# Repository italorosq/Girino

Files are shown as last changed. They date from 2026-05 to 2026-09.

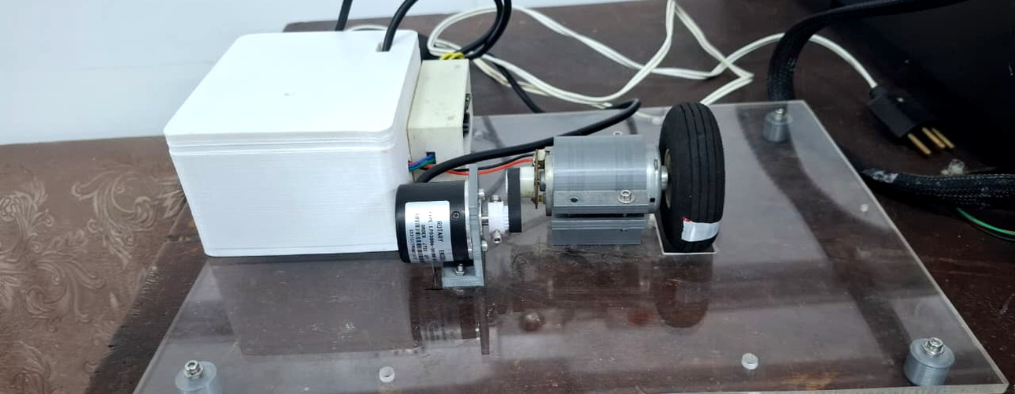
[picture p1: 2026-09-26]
docs/infografico/foto-bancada.jpg

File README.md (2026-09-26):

# Girino





Plataforma didática do **LaRA** (Laboratório de Robótica e Automação) para ensino de controle de motores DC. Integra microcontrolador com Wi-Fi, driver de potência L298N e encoder em uma bancada compacta para introdução prática à leitura de sensores, modulação PWM, controle PID e sintonia em malha fechada.

A interface web é embarcada no próprio ESP8266: o aluno conecta na rede do Girino e controla a bancada pelo navegador do celular ou notebook — sem instalar MATLAB, Python ou qualquer software, e sem depender de internet.

## Status do Projeto

| Componente | Status |
|---|---|
| Estrutura do repositório | ✅ Criada |
| Firmware (ESP8266) | ✅ Funcional — PID de velocidade/posição e auto-tune validados em bancada |
| Hardware (PCB — KiCad) | ✅ Projeto KiCad + arquivos de fabricação |
| Mecânico (caixa 3D) | ✅ Modelos STEP (caixa e tampa) |
| Documentação | ✅ |
| Exemplos didáticos | ✅ 5 exemplos |

## Funcionalidades

- **Access Point próprio** (`GIRINO_AP`, `http://192.168.4.1`) — funciona sem roteador e sem internet
- Controle PWM de motor DC via ESP8266 (4 kHz, 8 bits)
- Leitura de encoder incremental (LPD3806-600BM — 600 PPR)
- **Controle PID de velocidade (RPM) e de posição (graus)** em malha fechada
- **Auto-sintonia por relay feedback** (Åström-Hägglund) para velocidade e posição
- **Comparação de métodos de sintonia**: Ziegler-Nichols, Tyreus-Luyben e Cohen-Coon
- Interface web em 3 abas (Velocidade / Posição / Manual), com gráfico de resposta (Chart.js local) e exportação CSV
- **Console serial de comandos** — opera a bancada sem Wi-Fi
- **Auto-calibração do sentido** motor/encoder (fiação invertida corrigida em software)
- Atualização de firmware via OTA (ElegantOTA)
- Design compacto para bancada de laboratório

## Componentes de Hardware

| Componente | Descrição |
|---|---|
| ESP8266 WROOM | Microcontrolador com Wi-Fi (Access Point) |
| LPD3806-600BM | Encoder incremental, 600 pulsos/revolução (saída coletor aberto — pull-up 4,7k para 3,3 V) |
| L298N | Driver de potência do motor DC (ponte H) |
| Motor DC | Motor da bancada |
| Módulo conversão de tensão | Regulador de tensão para alimentação do circuito |

Ligações, pull-ups e montagem passo a passo em [`docs/hardware-assembly.md`](docs/hardware-assembly.md).

## Bancada Medida

| Grandeza | Valor |
|---|---|
| Zona morta do motor | ~60% de duty (abaixo disso o eixo não gira) |
| Região confiável | 70% de duty ≈ 400 RPM |
| Velocidade máxima | 100% ≈ 1950 RPM |
| Precisão de posição | ±2° (o erro residual de ~1–2° é folga mecânica da correia, não do PID) |

## Estrutura do Repositório

```
Girino/
├── firmware/          # Firmware ESP8266 (PlatformIO) + interface web (LittleFS em data/)
├── hardware/          # PCB KiCad, arquivos de fabricação (gerber/NC) e modelos 3D
├── mechanical/        # Peças 3D (em preparação)
├── docs/              # Documentação, pesquisa e infográfico
├── examples/          # Exemplos didáticos passo a passo
├── gallery/           # Fotos e renders do projeto
└── .github/           # Templates e CI/CD
```

## Início Rápido

Veja o guia completo em [`docs/getting-started.md`](docs/getting-started.md).

### Pré-requisitos

- [PlatformIO](https://platformio.org/) (extensão VSCode recomendada)
- Cabo USB para a gravação inicial do ESP8266
- Componentes e montagem: ver [`docs/hardware-assembly.md`](docs/hardware-assembly.md)

### Compilar e Gravar

```bash
cd firmware

# 1. Configurar o Access Point do Girino (SSID, senha e senha do OTA)
cp .env.example .env

# 2. Primeira gravação via USB: firmware + interface web (LittleFS)
pio run -t upload
pio run -t uploadfs

# 3. Conectar no Wi-Fi GIRINO_AP e abrir http://192.168.4.1

# 4. Atualizações seguintes via OTA (PC conectado ao GIRINO_AP)
pio run -t upload --upload-port 192.168.4.1
```

> **Importante:** `pio run -t upload` grava apenas o firmware. A interface web
> vive no LittleFS e é gravada com `pio run -t uploadfs` — obrigatório na
> primeira gravação e sempre que alterar arquivos de `firmware/data/`.

## Documentação

- [Guia de Início Rápido](docs/getting-started.md)
- [Montagem do Hardware](docs/hardware-assembly.md)
- [Guia do Firmware](firmware/README.md) — API REST, pinagem e console serial
- [Atualização OTA](docs/ota-update-guide.md)
- [Análise Comparativa](docs/analise-comparativa.md) — trabalhos relacionados e gap de pesquisa
- [Referências de Pesquisa](docs/referencias-pesquisa.md)
- [Plano PID](docs/plano-pid.md) — métodos de sintonia e arquitetura
- [Resumo UERJ Sem Muros](docs/resumo-uerj-sem-muros.md) — divulgação do projeto

## Exemplos Didáticos

| # | Exemplo | Descrição |
|---|---|---|
| 01 | [Controle Básico de Motor](examples/01-basic-motor-control/) | PWM para controlar velocidade do motor |
| 02 | [Leitura de Encoder](examples/02-encoder-reading/) | Ler pulsos e calcular velocidade |
| 03 | [Controle PID](examples/03-pid-speed-control/) | Malha fechada de velocidade |
| 04 | [OTA Web Update](examples/04-ota-web-update/) | Atualizar firmware via Wi-Fi |
| 05 | [PID Web Test](examples/05-pid-web-test/) | Teste prático de PID com painel web e gráfico |

## Contribuindo

Contribuições são bem-vindas! Veja o guia em [`CONTRIBUTING.md`](CONTRIBUTING.md).

## Licenças

Este projeto utiliza **tripla licença**:

| Tipo | Licença | Arquivo |
|---|---|---|
| Firmware (código) | **GPL-3.0** | [`LICENSE`](LICENSE) |
| Hardware (PCB, esquemático) | **CERN-OHL-S-2.0** | [`LICENSE`](LICENSE) |
| Documentação e imagens | **CC-BY-SA-4.0** | [`LICENSE`](LICENSE) |

## Equipe

Desenvolvido no **LaRA — Laboratório de Robótica e Automação** (UERJ).

## Agradecimentos

- Comunidade open-source ESP8266
- [ElegantOTA](https://github.com/ayushsharma82/ElegantOTA)
- [PlatformIO](https://platformio.org/)

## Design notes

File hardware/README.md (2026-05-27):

# Hardware — Girino

Design de PCB para a plataforma didática Girino, desenvolvido em KiCad.

## Estrutura

```
hardware/
├── kicad/          # Projeto KiCad (arquivos-fonte editáveis)
├── gerbers/        # Arquivos Gerber empacotados (.zip) para fabricação
├── bom/            # Bill of Materials (lista de materiais) em CSV
└── schematics/     # PDFs exportados do esquemático
```

## Componentes Principais

| Componente | Qtd | Descrição |
|---|---|---|
| ESP8266 WROOM | 1 | Microcontrolador Wi-Fi |
| LPD3806-600BM | 1 | Encoder incremental 600 PPR |
| Driver MOSFET | 1 | Módulo driver para motor DC |
| Regulador de tensão | 1 | Conversão de tensão para alimentação do circuito |

## Fabricação da PCB

### Gerando Gerbers no KiCad

1. Abra o projeto em `kicad/`
2. Vá em **File → Plot**
3. Selecione as camadas necessárias
4. Gere os arquivos drill
5. Empacote tudo em um `.zip` e salve em `gerbers/`

### Enviando para Fabricação

Arquivos `.zip` em `gerbers/` prontos para enviar a fabricantes como:
- [JLCPCB](https://jlcpcb.com/)
- [PCBWay](https://www.pcbway.com/)
- [Eletrrow](https://www.electrow.com/)

## Convenções

- Nomes de arquivo incluem versão: `gerbers-v1.0.zip`, `bom-v1.0.csv`
- Incluir URL do repositório no silkscreen da PCB
- Arquivos temporários de backup (`.bak`, `*-backups/`) são ignorados pelo git

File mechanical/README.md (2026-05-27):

# Peças Mecânicas — Girino

Modelos 3D para impressão da caixa/estrutura da plataforma Girino.

## Estrutura

```
mechanical/
├── cad/      # Arquivos-fonte FreeCAD (.FCStd) — editáveis
├── stl/      # Arquivos STL — prontos para impressão 3D
└── step/     # Arquivos STEP — para referência e montagem virtual
```

## Peças

| Peça | Arquivo | Descrição |
|---|---|---|
| Caixa superior | `girino-enclosure-top.stl` | Tampa da caixa protetora |
| Caixa inferior | `girino-enclosure-bottom.stl` | Base com fixações para componentes |
| Suporte encoder | `girino-encoder-mount.stl` | Suporte para fixação do encoder |

## Configurações de Impressão Recomendadas

| Parâmetro | Valor |
|---|---|
| Material | PLA ou PETG |
| Preenchimento | 20% (mínimo) |
| Perímetros | 3 |
| Altura de camada | 0.2 mm |
| Suportes | Conforme necessário |

## Editando os Modelos

1. Instale o [FreeCAD](https://www.freecad.org/)
2. Abra os arquivos `.FCStd` em `cad/`
3. Faça suas alterações
4. Exporte STL em **File → Export**
5. Salve o arquivo-fonte atualizado em `cad/`

## Convenções

- Nomes de arquivo descritivos em inglês
- STLs devem ser testados em slicer antes de commitar
- Manter arquivos STEP atualizados para referência

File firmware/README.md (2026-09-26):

# Firmware — Girino

Firmware para ESP8266 WROOM com controle PWM de motor DC, leitura de encoder e OTA.

## Requisitos

- [PlatformIO](https://platformio.org/) (CLI ou extensão VSCode)
- Cabo USB para gravação inicial
- Python 3 (para PlatformIO)

## Configuração Inicial

O Girino opera como **Access Point**: ele cria a própria rede Wi-Fi
(chamada `GIRINO_AP` por padrão) e os alunos conectam direto pelo
celular/notebook, sem precisar de roteador nem internet.

```bash
# 1. Copiar template de credenciais
cp .env.example .env

# 2. (Opcional) Ajustar nome e senha da rede criada pelo ESP:
#    WIFI_SSID="GIRINO_AP"
#    WIFI_PASSWORD="girino123"     # mínimo 8 caracteres
#    OTA_PASSWORD="senha_para_ota"
nano .env
```

Após conectar na rede do ESP, acesse `http://192.168.4.1`.

## Compilar e Gravar

### Primeira gravação (via USB)

```bash
# Compilar
pio run

# Compilar e gravar o firmware
pio run -t upload

# Gravar o filesystem (interface web em data/) — OBRIGATÓRIO na
# primeira gravação e sempre que alterar arquivos de data/
pio run -t uploadfs

# Monitor serial (Ctrl+] para sair)
pio device monitor
```

> **Importante:** `pio run -t upload` grava apenas o firmware. A interface
> web (`data/index.html`, `style.css`, `app.js`, `chart.umd.min.js`) vive
> no LittleFS e é gravada com `pio run -t uploadfs`. Se a página abrir com
> "index.html nao encontrado no LittleFS", falta o `uploadfs`.

### Console serial (controle sem Wi-Fi)

O firmware tem um console de comandos na própria porta serial — útil para
bancada, testes rápidos e quando não se quer usar o navegador. Abra o
monitor (`pio device monitor`) e digite `help`:

| Comando | Descrição |
|---|---|
| `help` | lista os comandos |
| `status` | modo, RPM, ângulo, pulsos, heap, IP |
| `enc` | leitura do encoder agora |
| `motor <fwd\|rev\|stop> [0-100]` | comando manual (cancela controladores) |
| `pid <kp> <ki> <kd> <sp>` | configura o PID de velocidade (RPM) |
| `pid start` / `pid stop` | liga/desliga a malha de velocidade |
| `pos <kp> <ki> <kd> <graus>` | configura o PID de posição |
| `pos start` / `pos stop` / `pos zero` | controle de posição / zera origem |
| `autotune <amp> <bias> <n> <sp>` | inicia o relay feedback (velocidade) |
| `autotune pos <amp> <n> <graus>` | inicia o relay feedback (posição, ±amp) |
| `autotune cancel` | cancela o experimento |
| `tune` | mostra Ku/Tu e ganhos ZN/TL/CC do último auto-tune |

Durante qualquer controlador ativo, a telemetria sai a 2 Hz no serial
(`[PID] SP/RPM/Out`, `[Pos] Alvo/Ângulo/Out`, `[AutoTune] RPM/relay`), e o
encoder reporta 1 Hz (`[Encoder] pulsos/p-s/rpm/ângulo`).

### Auto-calibração do sentido (fiação)

No primeiro movimento após o boot, o firmware aplica um pulso curto de
teste e observa a contagem do encoder:

- Contagem positiva → fiação normal (`[Motor] Sentido OK`)
- Contagem negativa → fiação invertida detectada e **corrigida em
  software** (`[Motor] Fiacao invertida detectada`) — não é preciso
  trocar fios: "horário" (FORWARD) sempre aumenta o ângulo medido

As malhas de velocidade e auto-tune usam |RPM| e funcionam com qualquer
polaridade; a calibração garante também o controle de posição.

### Atualizações subsequentes (via OTA)

Conecte o computador na rede do próprio ESP (`GIRINO_AP`) ou use a
interface web em `http://192.168.4.1/update`.

```bash
# Via OTA (computador conectado ao GIRINO_AP)
pio run -t upload --upload-port 192.168.4.1
```

> OTA e `uploadfs` não são a mesma coisa: OTA grava o **firmware**;
> alterações na interface web (pasta `data/`) exigem `pio run -t uploadfs`
> via USB.

## Arquitetura do Firmware

```
src/
├── main.cpp            # Loop principal, WiFi, web server, API REST
├── motor_control.cpp   # Controle PWM do motor
├── encoder.cpp         # Leitura do encoder via interrupção
├── pid.cpp             # Controle PID em malha fechada (50 Hz)
├── pid_autotune.cpp    # Auto-tune via relay feedback (Åström-Hägglund)
└── pid_tuning_rules.cpp # Regras de sintonia Ziegler-Nichols, Tyreus-Luyben e Cohen-Coon

include/
├── pins.h              # Mapeamento de GPIOs (centralizado)
├── config.h            # Constantes e configurações
├── motor_control.h     # Interface do módulo motor
├── encoder.h           # Interface do módulo encoder
├── pid.h               # Interface do módulo PID
├── pid_autotune.h      # Interface do auto-tune
└── pid_tuning_rules.h  # Interface das regras de sintonia
```

## API REST

| Endpoint | Método | Descrição |
|---|---|---|
| `/` | GET | Interface web de controle |
| `/api/motor` | POST | Comando do motor (`direction`, `speed`) |
| `/api/encoder` | GET | Leitura atual do encoder (`pulses`, `rpm`, `angle`) |
| `/api/status` | GET | Status (versão, heap, uptime, IP, clientes do AP, modo) |
| `/api/pid/config` | GET/POST | Configura/consulta ganhos e setpoint do PID de velocidade |
| `/api/pid/start` | POST | Inicia controle de velocidade em malha fechada |
| `/api/pid/stop` | POST | Para o PID, volta a malha aberta |
| `/api/pid/autotune` | GET/POST | Inicia/consulta experimento relay feedback (`plant=speed\|position`) |
| `/api/pid/tuning` | GET | Planta identificada (`plant`), Ku, Tu e sugestões `zn`/`tl`/`cc` |
| `/api/pid/tuning/apply` | POST | Aplica regra de sintonia (`method=ZN|TL|CC`) |
| `/api/pid/response` | GET | Última resposta ao degrau (tempo, setpoint, medida, `unit`) |
| `/api/position/config` | GET/POST | Configura/consulta ganhos e alvo do PID de posição (`target` em graus) |
| `/api/position/start` | POST | Inicia controle de posição (`target` opcional em graus) |
| `/api/position/stop` | POST | Para o controle de posição |
| `/api/position/zero` | POST | Define a posição atual como 0° (origem) |
| `/update` | GET | Interface OTA (ElegantOTA) |

### Exemplos de uso da API

```bash
# Ligar motor em 50% sentido horário (malha aberta)
curl -X POST http://192.168.4.1/api/motor -d "direction=forward&speed=50"

# Parar motor
curl -X POST http://192.168.4.1/api/motor -d "direction=stop&speed=0"

# Ler encoder
curl http://192.168.4.1/api/encoder

# Status do sistema
curl http://192.168.4.1/api/status

# Configurar PID (setpoint em RPM)
curl -X POST http://192.168.4.1/api/pid/config -d "kp=2.0&ki=5.0&kd=0.1&setpoint=100"

# Iniciar malha fechada
curl -X POST http://192.168.4.1/api/pid/start

# Iniciar auto-tune de VELOCIDADE (relay ±10% em torno de bias 90%, 3 ciclos, setpoint 100 RPM)
# O bias (pedestal) precisa vencer a zona morta do motor — o PWM mínimo
# que faz o eixo girar (medido nesta bancada: ~80%). Use `bias` entre esse
# valor e 95%, e `relay_amplitude` de forma que bias ± amplitude fique
# dentro de 0-100%.
curl -X POST http://192.168.4.1/api/pid/autotune -d "plant=speed&relay_amplitude=10&bias=90&cycles=3&setpoint=100"

# Iniciar auto-tune de POSIÇÃO (relé simétrico ±90% em torno do alvo 90°)
# O relé alterna horário/anti-horário; a amplitude precisa ficar acima da
# zona morta (~60%) para ambos os estados moverem o motor. Os ganhos
# resultantes estão em %/° (malha de posição).
curl -X POST http://192.168.4.1/api/pid/autotune -d "plant=position&relay_amplitude=90&cycles=3&target=90"

# Consultar resultado do auto-tune (inclui "plant": onde os ganhos se aplicam)
curl http://192.168.4.1/api/pid/autotune

# Aplicar Tyreus-Luyben
curl -X POST http://192.168.4.1/api/pid/tuning/apply -d "method=TL"

# Baixar resposta ao degrau
curl http://192.168.4.1/api/pid/response

# --- Controle de posição (ângulo) ---

# Zerar a posição atual (define origem 0°)
curl -X POST http://192.168.4.1/api/position/zero

# Configurar PID de posição (alvo 90°)
curl -X POST http://192.168.4.1/api/position/config -d "kp=1.0&ki=0.2&kd=0.05&target=90"

# Iniciar controle de posição
curl -X POST http://192.168.4.1/api/position/start

# Parar controle de posição
curl -X POST http://192.168.4.1/api/position/stop
```

## Pinagem

| GPIO | Pino NodeMCU | Função |
|---|---|---|
| GPIO5 | D1 | Encoder Canal A |
| GPIO4 | D2 | Encoder Canal B |
| GPIO14 | D5 | Motor Direção INB1 (alias IN3) |
| GPIO12 | D6 | Motor Direção INB2 (alias IN4) |
| GPIO13 | D7 | Motor PWM ENB |
| GPIO2 | LED | LED onboard (debug) |

> **Nota sobre o encoder:** o LPD3806 tem saída em coletor aberto — os
> canais A e B exigem resistores de pull-up externos de 4,7k para 3.3V
> (nunca 5V). Ver detalhes em [`docs/hardware-assembly.md`](../docs/hardware-assembly.md).

## Dependências

| Biblioteca | Versão | Descrição |
|---|---|---|
| ElegantOTA | ^3.1.5 | Interface web para atualização OTA |
| ESP8266WebServer | ^1.0 | Servidor HTTP embutido |

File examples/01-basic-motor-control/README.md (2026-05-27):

# Exemplo 01 — Controle Básico de Motor

Introdução ao controle PWM de um motor DC via ESP8266.

## Objetivos de Aprendizagem

- Entender o conceito de PWM (Pulse Width Modulation)
- Controlar a velocidade de um motor DC
- Controlar a direção de rotação

## Conceitos

### PWM (Modulação por Largura de Pulso)

O PWM controla a potência entregue ao motor variando o tempo que o sinal fica em nível alto (duty cycle).

- **Duty cycle 0%** → Motor parado
- **Duty cycle 50%** → Motor a meia velocidade
- **Duty cycle 100%** → Motor a velocidade máxima

### Controle de Direção

Usando dois pinos digitais de direcao (IN3 e IN4):

| IN3 | IN4 | Resultado |
|-----|-----|---|
| HIGH | LOW | Sentido horário |
| LOW | HIGH | Sentido anti-horário |
| LOW | LOW | Motor livre (parado) |
| HIGH | HIGH | Frenagem (freio) |

## Código

> Em breve — será adicionado com a implementação.

## Exercícios Propostos

1. Fazer o motor acelerar gradualmente de 0% a 100%
2. Alternar a direção a cada 3 segundos
3. Criar um "rampa" de aceleração suave

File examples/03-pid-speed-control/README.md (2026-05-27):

# Exemplo 03 — Controle PID de Velocidade

Implementação de controlador PID para manter velocidade constante do motor.

## Objetivos de Aprendizagem

- Entender o conceito de controle em malha fechada
- Implementar um controlador PID
- Sintonizar os ganhos Kp, Ki, Kd

## Conceitos

### Malha Fechada

```
  Setpoint ──→ [+] ──→ PID ──→ Motor ──→ Velocidade
                ↑ -                         │
                └──── Encoder (feedback) ───┘
```

### PID (Proporcional-Integral-Derivativo)

- **P (Proporcional):** Erro × Kp → reação proporcional ao erro
- **I (Integral):** Soma do erro × Ki → elimina erro em regime permanente
- **D (Derivativo):** Taxa de variação × Kd → amortecimento de oscilações

## Código

Este exemplo conceitual e o código executável de teste estão em:

- [`examples/05-pid-web-test/`](../05-pid-web-test/)

## Exercícios Propostos

1. Implementar apenas o P e observar o erro em regime
2. Adicionar I e eliminar o erro em regime permanente
3. Adicionar D e reduzir overshoot
4. Aplicar o método Ziegler-Nichols para sintonia
5. Testar resposta a perturbações (carga variável no motor)

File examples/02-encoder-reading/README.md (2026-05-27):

# Exemplo 02 — Leitura de Encoder

Introdução à leitura de encoder incremental LPD3806-600BM.

## Objetivos de Aprendizagem

- Entender o princípio de encoder incremental
- Ler pulsos via interrupção GPIO
- Calcular velocidade angular (RPM)

## Conceitos

### Encoder Incremental

O LPD3806-600BM gera 600 pulsos por revolução em dois canais (A e B) defasados em 90°:

- **Canal A sozinho** → Contagem de pulsos (velocidade)
- **Canais A+B** → Determinação de direção (quadratura)

### Interrupções

O ESP8266 suporta interrupções em GPIOs. Usamos interrupção no canal A e lemos o canal B na ISR para determinar a direção.

## Código

> Em breve — será adicionado com a implementação.

## Exercícios Propostos

1. Contar o número de voltas completas do motor
2. Medir a velocidade em RPM para diferentes níveis de PWM
3. Calcular a distância percorrida (se o motor aciona uma roda)

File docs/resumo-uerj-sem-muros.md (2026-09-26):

# Girino: plataforma didática de baixo custo para ensino de controle de motores DC via navegador

**Autor:** Ítalo Rosa Gonçalves
**Orientador:** Prof. Ângelo Mondaini Calvão
**Laboratório:** LaRA — Laboratório de Robótica e Automação (UERJ)
**Modalidade:** Estágio Interno Complementar
**ODS:** 4 — Educação de Qualidade

## Resumo

O ensino de controle exige prática experimental, mas bancadas comerciais são caras e as alternativas de baixo custo dependem de software proprietário ou instalações locais, restringindo o acesso dos estudantes. Alinhado ao ODS 4 (Educação de Qualidade), este trabalho desenvolve o Girino, plataforma didática de baixo custo para controle de motores DC, acessível apenas pelo navegador.

A bancada reúne microcontrolador com Wi-Fi, encoder de realimentação e driver de potência. O firmware implementa controle de velocidade e de posição em malha fechada, com auto-sintonia e comparação de métodos de sintonia. A interface web embarcada permite operar o motor e acompanhar a resposta em qualquer dispositivo, sem instalar nada, e o firmware é atualizado por OTA. O hardware também foi projetado no laboratório.

A bancada foi montada e validada: os controles de velocidade e posição operam em malha fechada, a auto-sintonia identifica o sistema e sugere ganhos, e a interface funciona sem internet. A caracterização do motor e a calibração da fiação também foram tratadas.

O Girino se mostra uma plataforma funcional e acessível, que dispensa MATLAB, Python ou qualquer instalação e facilita a manutenção das bancadas via OTA. Como continuidade, prevê-se a modelagem do sistema, a comparação experimental dos métodos e a avaliação pedagógica com alunos.

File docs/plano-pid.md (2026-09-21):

# Plano — Módulo PID e Auto-Tune

Planejamento do controle PID com auto-tune e comparação de métodos de sintonia para o artigo.

---

## 1. Métodos de Sintonia a Implementar

### Por que comparar métodos?

Todos os trabalhos relacionados usam **um único método** de sintonia, dependendo de MATLAB ou Python. Nenhum oferece comparação visual entre métodos diretamente no hardware. O Girino propõe que o aluno compare ZN, TL e CC no navegador — vendo diferenças de overshoot, tempo de acomodação e erro em regime.

### Métodos selecionados

| # | Método | Tipo | Referência | Por que incluir |
|---|---|---|---|---|
| 1 | **Ziegler-Nichols** | Regra (após relay) | Ziegler & Nichols, 1942 | Mais conhecido. Referência obrigatória em qualquer texto de controle. |
| 2 | **Tyreus-Luyben** | Regra (após relay) | Tyreus & Luyben, 1992 | Mais robusto que ZN, menor overshoot. Bom contraste didático. |
| 3 | **Cohen-Coon** | Regra (após relay) | Cohen & Coon, 1953 | Usado por Alexandre (2025) — permite comparação direta com literatura. |
| 4 | **Relay Feedback** | Auto-tune | Åström & Hägglund, 1984 | Método de identificação. Encontra Ku e Tu automaticamente. **Diferencial do Girino.** |
| 5 | **Manual** | Livre | — | Professor/aluno ajusta Kp, Ki, Kd via web. Maior valor didático. |

### Coeficientes de cada regra (a partir de Ku, Tu)

| Regra | Kp | Ti | Td |
|---|---|---|---|
| **Ziegler-Nichols** | 0.6 × Ku | Tu / 2.0 | Tu / 8.0 |
| **Tyreus-Luyben** | Ku / 2.2 | 2.2 × Tu | Tu / 6.3 |
| **Cohen-Coon** | (Ku/1.35) × (1 + Tu/(4×delay)) | Tu × f(delay) | Tu × g(delay) |

Nota: Cohen-Coon requer estimativa de atraso (dead time) — pode ser obtido via step test.

---

## 2. Fluxo de Auto-Tune (Relay Feedback)

```
Aluno clica "Auto-Tune" na interface web
       ↓
[1] Motor em velocidade nominal (setpoint inicial)
       ↓
[2] ESP8266 aplica relay: +d% se erro > 0, -d% se erro < 0
    (d = amplitude do relay, ex: 20% do PWM)
       ↓
[3] Sistema oscila em limite cycle
    Encoder mede período da oscilação → Tu (período crítico)
    Amplitude do relay × ganho do sensor → Ku (ganho crítico)
       ↓
[4] Calcula Ku e Tu pela média de N ciclos (N=3 a 5)
       ↓
[5] Oferece 3 opções de ganhos: ZN, TL, CC
    Aluno escolhe ou testa todas
       ↓
[6] PID carregado com Kp, Ki, Kd calculados
       ↓
[7] Resposta ao degrau registrada e exibida no gráfico web
       ↓
[8] Aluno pode comparar overshoot, settling time, steady-state error
```

### Parâmetros do Relay Feedback

| Parâmetro | Valor | Observação |
|---|---|---|
| Amplitude do relay (d) | 15–25% PWM | Ajustável. Motor não pode parar. |
| Número de ciclos (N) | 3–5 | Mais ciclos = mais preciso, mais demorado |
| Setpoint nominal | 50% velocidade | Ponto de operação para o experimento |
| Timeout | 30 segundos | Segurança — aborta se não oscilar |

---

## 3. Arquitetura do Firmware

### Novos arquivos

```
firmware/include/
├── pid.h                  → Estrutura PID (Kp, Ki, Kd, setpoint, limites)
├── pid_autotune.h         → Relay feedback (Ku, Tu, estado do experimento)
└── pid_tuning_rules.h     → Calcula Kp/Ki/Kd para ZN, TL, CC

firmware/src/
├── pid.cpp                → Cálculo PID com anti-windup + derivative-on-measurement
├── pid_autotune.cpp       → Máquina de estados do relay feedback
└── pid_tuning_rules.cpp   → Aplica regras de sintonia
```

### PID — Formulacao

```
Implementar forma posicional (standard):

u(t) = Kp × e(t) + Ki × ∫e(τ)dτ + Kd × de(t)/dt

Discreto (T = período de amostragem):

u[k] = Kp × e[k]
     + Ki × T × Σe[j]     (com anti-windup: clamp na integral)
     + Kd × (e[k] - e[k-1]) / T

Ou, para evitar derivative kick:
u[k] = Kp × e[k]
     + Ki × T × Σe[j]
     + Kd × (y[k] - y[k-1]) / T     (derivative on measurement)

Saída u[k] mapeada para PWM: 0 a MOTOR_PWM_RANGE (1023)
```

### Anti-windup

A integral do PID deve ser limitada para evitar saturação:
- Se `u[k] > max_output` → clamp integral em `max_output - Kp×e - Kd×de`
- Se `u[k] < min_output` → clamp integral similarmente

### Sample rate

| Taxa | Observação |
|---|---|
| 50 Hz (20 ms) | Boa para motor DC. ESP8266 aguenta facilmente. |
| 100 Hz (10 ms) | Se encoder de alta velocidade exigir. |
| 10 Hz (100 ms) | Taxa atual do encoder. Pode ser suficiente. |

**Recomendação:** 50 Hz (20ms). Encoder já amostra a 100ms — pode diminuir para 20ms no modo PID.

---

## 4. API REST — Novos Endpoints

| Endpoint | Método | Parâmetros | Descrição |
|---|---|---|---|
| `/api/pid/config` | POST | `kp`, `ki`, `kd`, `setpoint` | Configura ganhos e setpoint do PID |
| `/api/pid/config` | GET | — | Retorna config atual |
| `/api/pid/start` | POST | — | Liga controle em malha fechada |
| `/api/pid/stop` | POST | — | Desliga PID, volta a malha aberta |
| `/api/pid/autotune` | POST | `relay_amplitude`, `cycles` | Inicia experimento relay feedback |
| `/api/pid/autotune` | GET | — | Status do auto-tune (running/done/results) |
| `/api/pid/tuning` | GET | — | Retorna Ku, Tu + sugestões ZN/TL/CC |
| `/api/pid/tuning/apply` | POST | `method` (ZN/TL/CC) | Aplica regra de sintonia escolhida |
| `/api/pid/response` | GET | — | Última resposta ao degrau (array tempo, setpoint, velocidade) |

### Exemplo de uso

```bash
# 1. Iniciar auto-tune
curl -X POST http://192.168.1.100/api/pid/autotune \
  -d "relay_amplitude=20&cycles=3"

# 2. Ver resultados
curl http://192.168.1.100/api/pid/autotune
# → {"status":"done","ku":5.2,"tu":0.35}

# 3. Ver sugestões
curl http://192.168.1.100/api/pid/tuning
# → {"ku":5.2,"tu":0.35,
#     "ZN":{"kp":3.12,"ki":17.83,"kd":0.14},
#     "TL":{"kp":2.36,"ki":4.55,"kd":0.06},
#     "CC":{"kp":3.85,"ki":15.20,"kd":0.12}}

# 4. Aplicar Tyreus-Luyben
curl -X POST http://192.168.1.100/api/pid/tuning/apply \
  -d "method=TL"

# 5. Iniciar malha fechada
curl -X POST http://192.168.1.100/api/pid/start \
  -d "setpoint=50"

# 6. Coletar resposta ao degrau
curl http://192.168.1.100/api/pid/response
# → {"data":[[0,0],[0.02,5],...,[3.0,49.8]],"setpoint":50}
```

---

## 5. Interface Web — Componentes Novos

### Painel de PID (adicionar à página principal)

```
┌─────────────────────────────────────┐
│  Controle PID                       │
│                                     │
│  Setpoint: [____] RPM               │
│  Kp: [____]  Ki: [____]  Kd: [____] │
│                                     │
│  [▶ Iniciar PID]  [⏹ Parar]         │
│  [🔧 Auto-Tune]  [📊 Step Response] │
│                                     │
│  Método de sintonia:                │
│  ○ Ziegler-Nichols                  │
│  ○ Tyreus-Luyben (recomendado)      │
│  ○ Cohen-Coon                       │
│  ○ Manual                           │
│                                     │
│  ┌─────────────────────────────┐    │
│  │  Gráfico: Tempo vs RPM      │    │
│  │  (setpoint + resposta real)  │    │
│  │  ~~~~~~~~~~~~~~~~~~~~~~~~    │    │
│  └─────────────────────────────┘    │
│                                     │
│  Resultados Auto-Tune:              │
│  Ku = 5.2  Tu = 0.35s              │
│  Overshoot: 12%  Settling: 1.8s     │
└─────────────────────────────────────┘
```

### Biblioteca de gráficos

Usar **Chart.js** (CDN, leve, sem instalação):
- Gráfico de linha em tempo real
- Eixo X: tempo (s), Eixo Y: RPM
- Linha tracejada: setpoint
- Linha sólida: velocidade real
- Exportar dados como CSV

---

## 6. Estrutura Didática (Exemplos Progressivos)

| # | Exemplo | Conceito | Atividade do Aluno |
|---|---|---|---|
| 01 | Controle básico de motor | PWM, duty cycle | Variar PWM e observar velocidade |
| 02 | Leitura de encoder | Interrupção, quadratura | Contar pulsos, calcular RPM |
| 03 | Curva do motor (malha aberta) | Modelagem empírica | Aplicar PWM de 0 a 100%, plotar curva RPM vs PWM |
| 04 | PID manual | Controle em malha fechada | Ajustar Kp, Ki, Kd e observar resposta |
| 05 | Auto-tune | Identificação de sistemas | Executar relay feedback, obter Ku e Tu |
| 06 | Comparação de métodos | ZN vs TL vs CC | Aplicar cada método, comparar gráficos |

### Valor didático da comparação de métodos

O aluno aprende que:
- ZN tem resposta rápida mas muito overshoot
- TL é mais lento mas sem oscilação
- CC é intermediário
- Manual pode ser melhor se o aluno entende o sistema
- Não existe "melhor método" — depende do critério (velocidade, robustez, etc.)

---

## 7. Comparação com Trabalhos Existentes

| Aspecto | Alexandre 2025 | Cabral 2025 | MotoShield | OpenMCT | **Girino** |
|---|---|---|---|---|---|
| Método de sintonia | Cohen-Coon | z-domain (MATLAB) | MATLAB sysID | Coeficientes GUI | **Auto-tune + 3 regras + manual** |
| Auto-tune embarcado | ❌ | ❌ | ❌ | ❌ | **✅ (Relay Feedback)** |
| Comparação de métodos | ❌ | ❌ | ❌ | ❌ | **✅ (ZN vs TL vs CC)** |
| Visualização | SCADA externo | MATLAB | MATLAB | Python/Qt | **Navegador web** |
| Software necessário | SCADA | MATLAB | MATLAB | Python+Qt | **Nenhum** |

### Argumento para o paper

> "Enquanto plataformas existentes usam um único método de sintonia dependente de software externo (MATLAB, Python), o Girino implementa auto-tune embarcado via relay feedback (Åström-Hägglund) e permite comparação direta de três regras clássicas (Ziegler-Nichols, Tyreus-Luyben, Cohen-Coon) através de interface web — sem instalação de qualquer software."

---

## 8. Pendências para o Artigo (Checklist)

- [x] Levantamento bibliográfico (~70 referências)
- [x] Análise comparativa dos trabalhos relacionados
- [x] Planejamento dos métodos de sintonia
- [x] Implementar PID no firmware (pid.h + pid.cpp)
- [x] Implementar auto-tune (pid_autotune.h + pid_autotune.cpp)
- [x] Implementar regras de sintonia (ZN, TL, CC)
- [x] Adicionar endpoints API REST para PID
- [ ] Interface web com gráfico de resposta ao degrau (UI pronta; validar com hardware real)
- [ ] Modelagem matemática do sistema motor+encoder
- [ ] Testes experimentais: comparar ZN vs TL vs CC
- [ ] Avaliação pedagógica com alunos
- [ ] Redação do artigo

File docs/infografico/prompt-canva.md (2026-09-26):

# Prompt para a IA do Canva — infográfico 60 × 15 cm

Uso: no Canva Pro, crie um design em **Custom size → 60 × 15 cm**, suba `foto-bancada.jpg`, `infografico-uerj-sem-muros-60x15.png` (referência) e, no Brand Kit, as cores e as fontes de `fontes/` (Source Sans 3). Cole o prompt abaixo na IA e substitua os textos gerados pelos textos exatos do prompt. QR: Apps → QR Code → `github.com/italorosq/Girino`. Exporte PDF Print para a gráfica.

Atenção: a exportação PNG do Canva pode sair abaixo de 300 dpi; para o SDA, use o PNG de `docs/images/` (mesmo layout, 7087 × 1772 px).

---

Crie um infográfico horizontal (banner) de 60 × 15 cm, em português do Brasil, sobre um projeto acadêmico de engenharia, para a 23ª Semana de Graduação / 34ª UERJ Sem Muros. Público: banca e visitantes. Estilo institucional, técnico e sóbrio — nada infantil, nada de clip-art, sem sombras fortes nem excesso de gradientes. Fundo geral #E4EBF3; painéis brancos com borda fina #D9E3EF e cantos arredondados.

TEMA: modernização das plataformas robóticas do LaRA (Laboratório de Robótica e Automação — UERJ / CETREINA / EIC). O Girino é o PRIMEIRO MÓDULO ENTREGUE dessa modernização — não é um projeto separado.

Título (usar exatamente): "Modernização de Plataformas Robóticas e Desenvolvimento de Infraestrutura para Experimentação em Algoritmos de Robótica".

LAYOUT — 6 painéis lado a lado, com pequenos espaços entre eles (~0,1 cm) e estas larguras relativas:
1. Identidade — 15,6% (fundo azul-escuro #0B2C57, texto branco)
2. Problema — 12,7% (barra vermelha #C0392B)
3. Tese e Objetivo — 15,6% (barra azul #1660A8)
4. Método — 22,0% (barra azul #1660A8)
5. Resultados — 19,1% (barra verde-água #0E9594)
6. Impacto — 14,2% (barra verde-água #0E9594)
Cada painel tem uma barra vertical colorida de ~14 px ao lado do título da seção. Toques sutis de vida: sombra leve nos painéis, faixa de fundo tingida no cabeçalho de cada painel na cor da seção (~6% de opacidade), ícones dentro de badges circulares claros, chips com preenchimento tingido, e nos cartões de números um numeral gigante "fantasma" ao fundo (~7% de opacidade). Ícones lineares, traço fino, sem preenchimento.

PAINEL 1 — IDENTIDADE (azul-escuro #0B2C57, texto branco):
- Etiqueta no topo, em âmbar #F2A100: EIC · CETREINA/UERJ · LaRA
- Título acima, grande (ocupa cerca de 6 linhas)
- Subtítulo: Modernizar e manter o que a instituição já tem: o Girino como primeiro produto e o caminho documentado para quem vier depois.
- Quatro chips: Modernizar o que existe · Girino: primeiro produto · Plataforma aberta · Formação do bolsista
- Na base: um QR code branco com a legenda "Código aberto" (apontando para github.com/italorosq/Girino) e um mascote discreto de girino (tadpole) em traço fino branco, bem apagado, como marca d'água.

PAINEL 2 — PROBLEMA (vermelho #C0392B), 4 itens com ícones lineares:
1. Equipamento preservado e fora de uso — A estrutura continua íntegra, mas o sistema de controle envelhece, o suporte do fabricante acaba e as peças saem de linha. (ícone: base móvel com braço)
2. Camada de controle fechada — O que existe não admite modificação, expansão nem integração com as ferramentas atuais. (ícone: cadeado sobre conector)
3. Tentativas anteriores abandonadas — A curva de aprendizado inicial não se sustentou e o equipamento voltou para a prateleira. (ícone: linha do tempo interrompida por um X)
4. Formação sem prática — Controle, cinemática e processamento de sinais estudados sem contato com hardware real, ruído e limitações. (ícone: livro aberto com circuito)

PAINEL 3 — TESE E OBJETIVO (azul #1660A8):
- Duas premissas em destaque (com aspas decorativas grandes ao fundo, bem apagadas):
  "Manter o equipamento em uso vale tanto quanto adquiri-lo."
  "Baixar a barreira de entrada é o que devolve o equipamento ao uso."
- OBJETIVO: Modernizar e manter as plataformas do laboratório, com controladores abertos de baixo custo, e transformar o processo em formação técnica para o bolsista e em recurso aberto para a comunidade acadêmica. O Girino é o primeiro produto. (destacar a última frase)
- Nota de rodapé, em itálico: Bolsista recém-iniciado e sem verba de material: o que já roda usa os componentes que o laboratório tem em estoque.

PAINEL 4 — MÉTODO (azul #1660A8), 4 etapas numeradas em círculo:
1. Caracterizar o que existe — Entender a estrutura, medir o que ainda funciona e registrar o que precisa ser trocado.
2. Começar pelo Girino — Um motor, um driver e um encoder, com interface no navegador, para validar o caminho em escala pequena.
3. Avançar por etapas — Cada função nova é validada em bancada antes de entrar no equipamento, e o que dá errado é registrado junto com a solução.
4. Documentar enquanto acontece — Esquemas, medições, listas de materiais e código aberto, para que a próxima pessoa não recomece do zero.
- Dois chips: "Ciclos: bancada → plataforma montada → uso real" e "Adaptações mecânicas impressas em 3D no próprio laboratório"

PAINEL 5 — RESULTADOS (verde-água #0E9594), 4 métricas grandes em grade 2 × 2 (número gigante + rótulo):
- 2 — malhas PID em bancada: velocidade e posição, com auto-sintonia embarcada
- 3 — métodos de sintonia comparados: Ziegler-Nichols, Tyreus-Luyben e Cohen-Coon
- 600 — pulsos por revolução no encoder incremental lido por interrupção
- 0 — programas a instalar: o controle é feito pelo navegador, sem internet
- Abaixo das métricas, uma FOTO REAL da bancada (anexada): motor DC com encoder e roda, driver e caixa impressa em 3D sobre base de acrílico. NÃO substituir por banco de imagens. Legenda sobre a foto: "Bancada de validação do Girino — ESP8266 + driver MOSFET + encoder LPD3806-600BM"
- Faixa escura no pé do painel: Sem verba de material: componentes do estoque do laboratório · PID e auto-sintonia validados em bancada · placa de circuito impresso em projeto no KiCad e caixa em 3D nas próximas etapas

PAINEL 6 — IMPACTO (verde-água #0E9594), 4 itens numerados:
1. Equipamento de volta ao uso — Em vez de comprar de novo, manter e modernizar o que a instituição já pagou.
2. Entrada barata para a robótica — O Girino serve a disciplinas, extensão e trabalhos de conclusão, e a bancada é replicável em outros laboratórios.
3. Formação técnica — O bolsista percorre o ciclo completo de um projeto de sistemas embarcados, da medição de bancada à documentação de entrega.
4. Método replicável — Caracterizar o que existe, adotar arquitetura aberta e documentar em processo contínuo, o que serve a outros equipamentos da instituição.
- Faixa âmbar no pé: Diversidade que inspira, conhecimento que transforma

HIERARQUIA DE TEXTO (para 60 × 15 cm, legível a ~1,5 m):
- Título do trabalho: ~19–20 pt (≈ 7,5 mm de altura)
- Títulos dos painéis: ~14 pt (≈ 5 mm)
- Corpo: 11–12 pt (≈ 3,8–4,2 mm) — nunca abaixo de ~10 pt
- Números das métricas: ~36 pt (≈ 12,7 mm)
- Chips: ~10 pt

TIPOGRAFIA E CORES:
- Fonte sem serifa Source Sans 3 (ou Source Sans Pro)
- Paleta: #0B2C57 (azul-escuro), #1660A8 (azul), #0E9594 (verde-água), #F2A100 (âmbar), #C0392B (vermelho), #D9E3EF (borda), #E4EBF3 (fundo)

FATOS QUE PODEM SER AFIRMADOS (não inventar além disso): firmware em modo hardware real (sem simulador); PID de velocidade e de posição em malha fechada com auto-sintonia embarcada, validados em bancada; 3 métodos de sintonia comparados; encoder de 600 pulsos por revolução lido por interrupção; controle pelo navegador, sem instalar nada e sem internet.

NÃO INCLUIR: nomes de autores, orientador, curso ou unidade acadêmica (ficam no cabeçalho do pôster, fora do infográfico); licenças; referências bibliográficas; metragem do laboratório; modelo, dimensões ou graus de liberdade dos equipamentos a modernizar; qualquer número, resultado ou prêmio que não esteja neste prompt.

---

## Refinamentos (se a IA do Canva fugir do alvo)

- "Mantenha este layout, mas troque toda a tipografia por Source Sans Pro e reduza as sombras."
- "O painel Resultados deve ficar exatamente 2 × 2 com 4 cartões iguais; aumente os números em 20%."
- "Deixe os ícones lineares, traço fino, dentro de círculos claros, sem preenchimento."
- "Aumente todo o corpo de texto em ~10% — precisa ser legível a 1,5 m no banner."

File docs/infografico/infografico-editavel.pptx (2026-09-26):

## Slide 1

EIC · CETREINA/UERJ · LaRA

Modernização de Plataformas Robóticas e Desenvolvimento de Infraestrutura para Experimentação em Algoritmos de Robótica

Modernizar e manter o que a instituição já tem: o Girino como primeiro produto e o caminho documentado para quem vier depois.

Modernizar o que existe

Girino: primeiro produto

Plataforma aberta

Formação do bolsista

Código aberto
github.com/italorosq/Girino

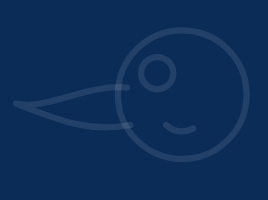
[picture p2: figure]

Problema

Equipamento preservado e fora de uso

A estrutura continua íntegra, mas o sistema de controle envelhece, o suporte do fabricante acaba e as peças saem de linha.

Camada de controle fechada

O que existe não admite modificação, expansão nem integração com as ferramentas atuais.

Tentativas anteriores abandonadas

A curva de aprendizado inicial não se sustentou e o equipamento voltou para a prateleira.

Formação sem prática

Controle, cinemática e processamento de sinais estudados sem contato com hardware real, ruído e limitações.

Tese e Objetivo

Manter o equipamento em uso vale tanto quanto adquiri-lo.

Baixar a barreira de entrada é o que devolve o equipamento ao uso.

OBJETIVO

Modernizar e manter as plataformas do laboratório, com controladores abertos de baixo custo, e transformar o processo em formação técnica para o bolsista e em recurso aberto para a comunidade acadêmica.
O Girino é o primeiro produto.

Bolsista recém-iniciado e sem verba de material: o que já roda usa os componentes que o laboratório tem em estoque.

Método

Ciclos: bancada → plataforma montada → uso real

Adaptações mecânicas impressas em 3D no próprio laboratório

Caracterizar o que existe

Entender a estrutura, medir o que ainda funciona e registrar o que precisa ser trocado.

Começar pelo Girino

Um motor, um driver e um encoder, com interface no navegador, para validar o caminho em escala pequena.

Resultados

Bancada de validação do Girino — ESP8266 + driver MOSFET + encoder LPD3806-600BM

Sem verba de material: componentes do estoque do laboratório · PID e auto-sintonia validados em bancada · placa de circuito impresso em projeto no KiCad e caixa em 3D nas próximas etapas

2

malhas PID em bancada: velocidade e posição, com auto-sintonia embarcada

3

métodos de sintonia comparados: Ziegler-Nichols, Tyreus-Luyben e Cohen-Coon

Impacto

Equipamento de volta ao uso

Em vez de comprar de novo, manter e modernizar o que a instituição já pagou.

Entrada barata para a robótica

O Girino serve a disciplinas, extensão e trabalhos de conclusão, e a bancada é replicável em outros laboratórios.

Formação técnica

O bolsista percorre o ciclo completo de um projeto de sistemas embarcados, da medição de bancada à documentação de entrega.

Método replicável

Caracterizar o que existe, adotar arquitetura aberta e documentar em processo contínuo, o que serve a outros equipamentos da instituição.

Diversidade que inspira, conhecimento que transforma

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
pulsos por revolução no encoder incremental lido por interrupção

0

programas a instalar: o controle é feito pelo navegador, sem internet

Avançar por etapas

Cada função nova é validada em bancada antes de entrar no equipamento, e o que dá errado é registrado junto com a solução.

Documentar enquanto acontece

Esquemas, medições, listas de materiais e código aberto, para que a próxima pessoa não recomece do zero.

600

0

3

4

3


4

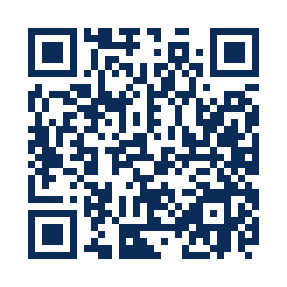
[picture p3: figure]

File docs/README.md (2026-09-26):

# Documentação — Girino

Documentação técnica da plataforma didática Girino.

## Guias

| Documento | Descrição |
|---|---|
| [Início Rápido](getting-started.md) | Setup completo do zero |
| [Montagem do Hardware](hardware-assembly.md) | Passo a passo de montagem |
| [Guia do Firmware](firmware-guide.md) | Compilação e gravação |
| [Atualização OTA](ota-update-guide.md) | Atualizar firmware via Wi-Fi |

## Pesquisa e Publicação

| Documento | Descrição |
|---|---|
| [Referências de Pesquisa](referencias-pesquisa.md) | Levantamento bibliográfico (~70 referências) para artigo |
| [Análise Comparativa](analise-comparativa.md) | Review dos trabalhos relacionados, gap analysis e estratégia de publicação |
| [Plano PID](plano-pid.md) | Métodos de sintonia, auto-tune, arquitetura e exemplos didáticos |

## Eventos

| Documento | Descrição |
|---|---|
| [Resumo UERJ Sem Muros](resumo-uerj-sem-muros.md) | Resumo do projeto para submissão à UERJ Sem Muros (1000–2000 caracteres) |
| [Infográfico UERJ Sem Muros](images/infografico-uerj-sem-muros.png) | Infográfico de divulgação do projeto (PNG, 1080×1350) |

## Recursos

- `images/` — Diagramas, esquemas de ligação, fotos
- `datasheets/` — Datasheets dos componentes utilizados

## Contribuindo com Documentação

- Use Markdown (`.md`) para todos os textos
- Imagens em `images/` com nomes descritivos
- Mantenha os guias atualizados quando o hardware ou firmware mudar

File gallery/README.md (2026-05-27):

# Galeria — Girino

Fotos, renders e vídeos da plataforma Girino.

## Estrutura

```
gallery/
├── photos/    # Fotos do hardware montado
└── videos/    # Vídeos de demonstração
```

## Contribuindo

- Use nomes descritivos para os arquivos
- Fotos em alta resolução (mínimo 1920x1080)
- Inclua legendas quando relevante

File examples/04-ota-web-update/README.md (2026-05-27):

# Exemplo 04 — Atualização OTA via Web

Demonstração de como usar OTA para atualizar o firmware sem cabo USB.

## Objetivos de Aprendizagem

- Entender o conceito de OTA (Over-The-Air)
- Configurar e usar ElegantOTA
- Atualizar firmware remotamente

## Conceitos

### OTA (Over-The-Air)

Permite atualizar o firmware do ESP8266 via Wi-Fi, sem conexão física. Útil para:
- Dispositivos instalados em locais de difícil acesso
- Atualização em lote de múltiplos dispositivos
- Manutenção remota em laboratório

### ElegantOTA

Biblioteca que fornece interface web para upload de firmware com:
- Barra de progresso em tempo real
- Suporte a firmware e filesystem
- Reinicialização automática após upload

## Código

> Em breve — será adicionado com a implementação.

## Exercícios Propostos

1. Fazer a primeira gravação via USB e subsequentes via OTA
2. Modificar a interface web e atualizar via OTA
3. Configurar senha OTA para segurança

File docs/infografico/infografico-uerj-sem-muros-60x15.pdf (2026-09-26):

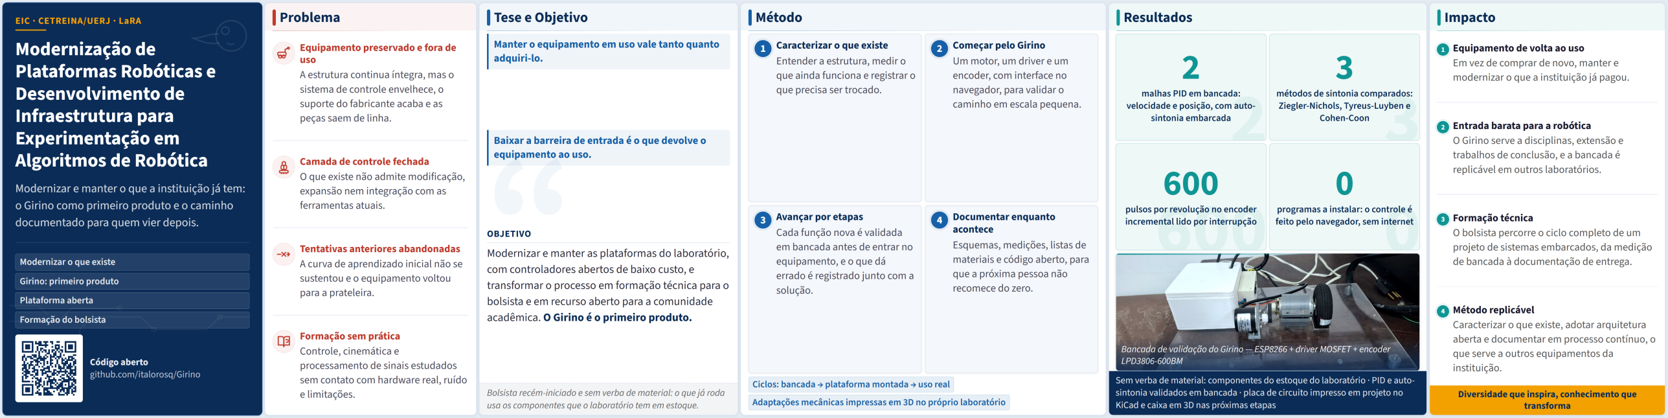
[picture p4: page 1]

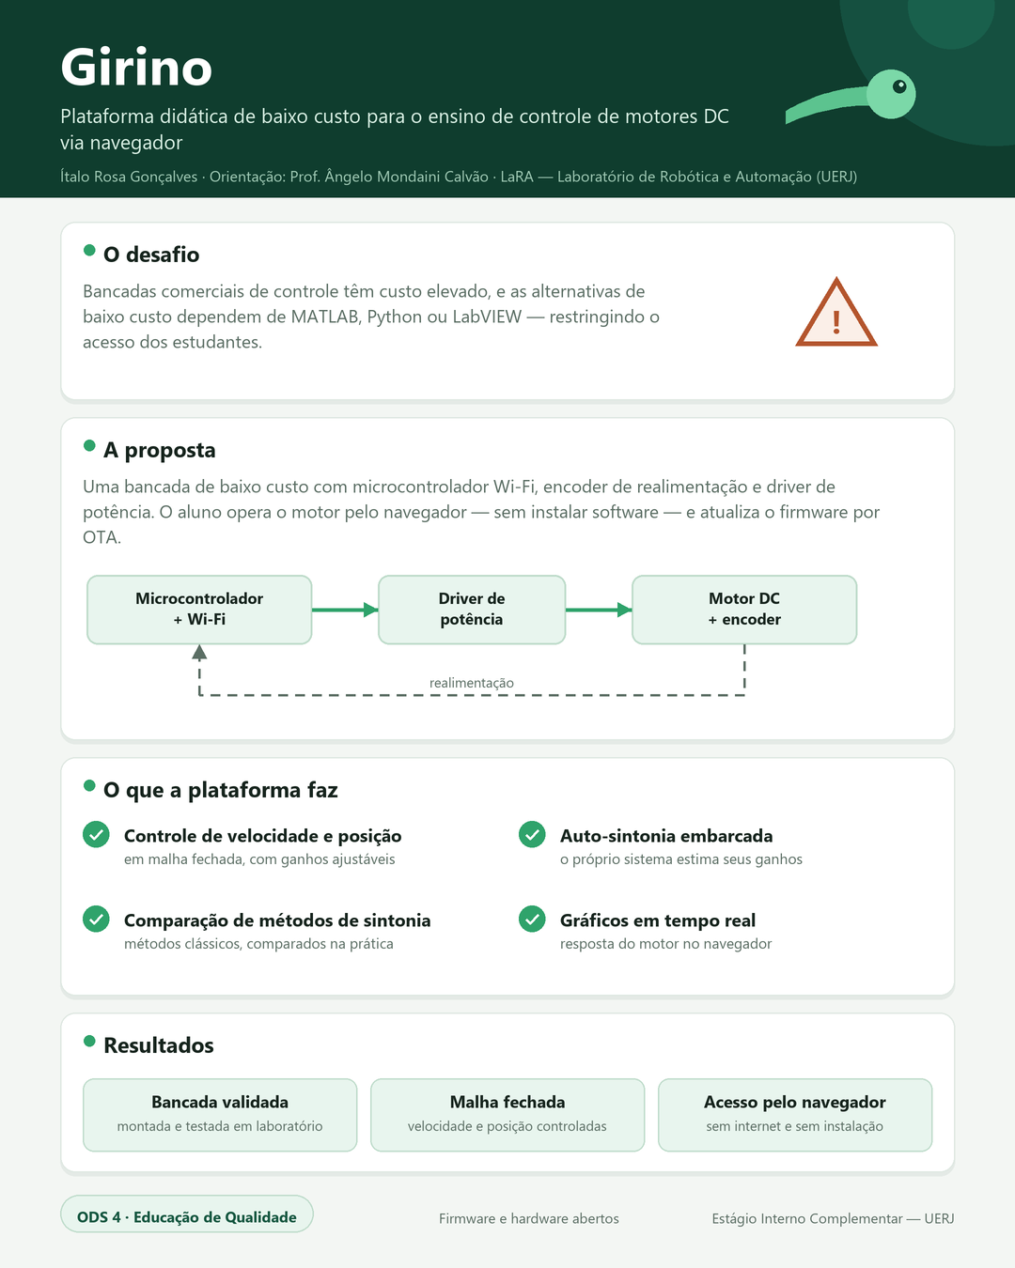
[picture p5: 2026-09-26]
docs/images/infografico-uerj-sem-muros.png

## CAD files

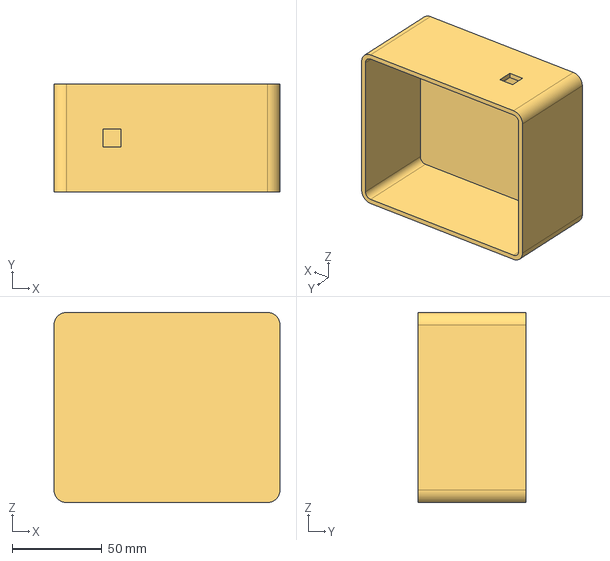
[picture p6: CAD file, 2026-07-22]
hardware/3d models/caixa.step
126.0 x 60.0 x 106.0 mm

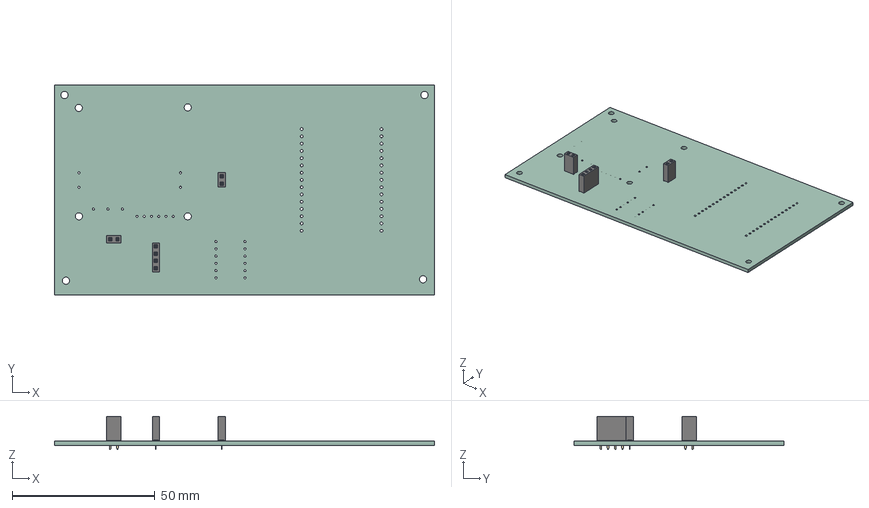
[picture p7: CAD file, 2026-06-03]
hardware/kicad/.step
133.0 x 73.5 x 11.6 mm
PinSocket_1x04_P2.54mm_Vertical
PinSocket_1x02_P2.54mm_Vertical x 2
pcb_copper
pcb_PCB

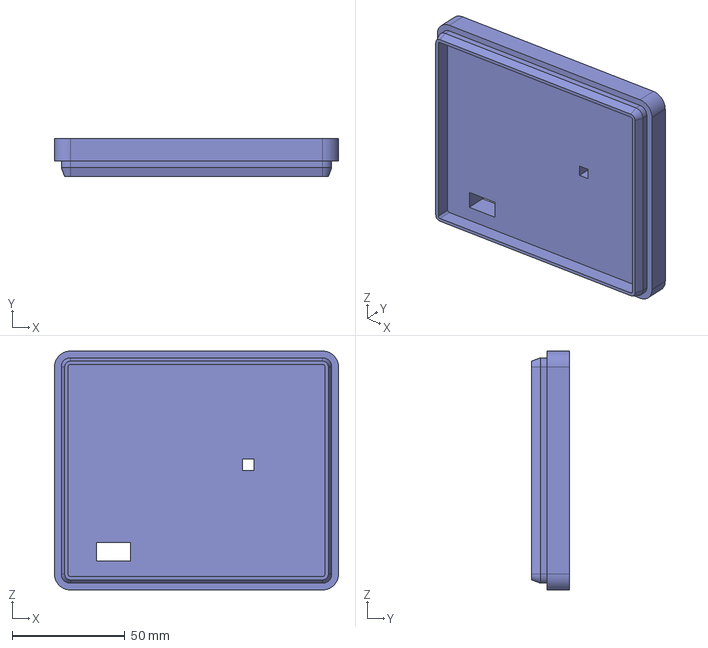
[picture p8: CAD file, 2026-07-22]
hardware/3d models/tampa.step
126.0 x 17.0 x 106.0 mm

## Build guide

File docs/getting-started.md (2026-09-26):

# Guia de Início Rápido — Girino

## Visão Geral

Este guia orienta você desde a montagem do hardware até o primeiro controle do motor via interface web. O Girino cria a própria rede Wi-Fi (**Access Point**): não é preciso roteador nem internet — basta conectar no celular ou notebook e abrir a página de controle.

## Pré-requisitos

### Ferramentas

- Computador com [VSCode](https://code.visualstudio.com/) + extensão [PlatformIO](https://platformio.org/)
- Cabo USB micro-B
- Ferro de solda (para montagem do hardware)

### Componentes

| Componente | Qtd | Notas |
|---|---|---|
| ESP8266 WROOM | 1 | Módulo com antena PCB |
| Encoder LPD3806-600BM | 1 | 600 pulsos/revolução |
| Driver L298N | 1 | Ponte H para o motor DC |
| Motor DC | 1 | Qualquer motor DC pequeno |
| Módulo conversão de tensão | 1 | Para alimentação do circuito |
| Resistores 4,7k | 2 | Pull-up dos canais A/B do encoder para 3,3 V |
| Fonte de alimentação | 1 | Compatível com o motor e circuito |
| Cabos jumper | vários | Para conexões |
| Protoboard | 1 | Opcional — PCB recomendada |

## Passo 1: Montagem do Hardware

Siga o guia detalhado em [hardware-assembly.md](hardware-assembly.md).

### Esquema de Ligação Rápido

```
ESP8266 WROOM
├── D1 (GPIO5)  ← Encoder A (fio amarelo) + pull-up 4,7k para 3.3V
├── D2 (GPIO4)  ← Encoder B (fio verde)  + pull-up 4,7k para 3.3V
├── D5 (GPIO14) → Motor DIR IN3 (L298N)
├── D6 (GPIO12) → Motor DIR IN4 (L298N)
├── D7 (GPIO13) → Motor PWM ENB (L298N)
├── Vin          ← 5V (módulo conversão)
├── GND         ← GND comum
└── USB         ← Para gravação inicial
```

> O encoder LPD3806 tem saída em **coletor aberto**: sem os pull-ups externos de 4,7k (para 3,3 V, nunca 5 V) o ESP8266 não lê os pulsos. Detalhes e justificativa em [hardware-assembly.md](hardware-assembly.md).

## Passo 2: Configurar o Firmware

```bash
# Clonar o repositório
git clone https://github.com/LaRA-UERJ/Girino.git
cd Girino/firmware

# Copiar o template de configuração do Access Point
cp .env.example .env
nano .env
```

O `.env` **não** são credenciais de roteador — são as da rede que o próprio Girino cria:

| Variável | Padrão | Descrição |
|---|---|---|
| `WIFI_SSID` | `GIRINO_AP` | Nome da rede Wi-Fi criada pelo ESP8266 |
| `WIFI_PASSWORD` | `girino123` | Senha dessa rede (mínimo 8 caracteres; senha curta sobe rede aberta) |
| `OTA_PASSWORD` | `girino_ota` | Senha da página de atualização OTA |

## Passo 3: Compilar e Gravar

```bash
# Compilar (opcional, o upload já compila)
pio run

# Gravar o firmware via USB
pio run -t upload

# Gravar a interface web (LittleFS) — obrigatório na primeira gravação
pio run -t uploadfs

# Monitor serial (115200 baud; Ctrl+] para sair)
pio device monitor
```

Você deverá ver no monitor serial:

```
=== Girino v0.1.0 ===
LaRA — Laboratório de Robótica e Automação
[Motor] Inicializado
[Encoder] Inicializado — LPD3806-600BM (600 PPR)
[PID] Inicializado
[Pos] Controle de posicao inicializado (angulo)
[AutoTune] Inicializado
[WiFi] Access Point 'GIRINO_AP' ativo
[WiFi] IP: 192.168.4.1
[LittleFS] Filesystem montado
Servidor HTTP + OTA iniciado
[Console] Digite 'help' para os comandos (115200 baud)
Sistema inicializado com sucesso!
Pagina de controle: http://192.168.4.1
OTA: http://192.168.4.1/update
```

> Se a página abrir com **"index.html nao encontrado no LittleFS"**, faltou o `pio run -t uploadfs` (a interface web é gravada separadamente do firmware).

## Passo 4: Controlar via Web

1. No celular ou notebook, conecte na rede Wi-Fi **`GIRINO_AP`** (senha definida no `.env`)
2. Abra o navegador em **`http://192.168.4.1`**
3. Use as abas **Velocidade**, **Posição** ou **Manual**; o botão **PARAR** no cabeçalho desliga o motor a qualquer momento

## Alternativa sem Wi-Fi: Console Serial

Com o monitor serial aberto (`pio device monitor`), digite `help`. Os principais comandos:

| Comando | Descrição |
|---|---|
| `status` | modo, RPM, ângulo, pulsos, heap e IP |
| `motor <fwd\|rev\|stop> [0-100]` | comando manual do motor |
| `pid <kp> <ki> <kd> <sp>` / `pid start` | PID de velocidade (RPM) |
| `pos <kp> <ki> <kd> <graus>` / `pos start` / `pos zero` | PID de posição (ângulo) |
| `autotune <amp> <bias> <n> <sp>` | auto-sintonia da velocidade |
| `autotune pos <amp> <n> <graus>` | auto-sintonia da posição |
| `tune` | mostra Ku/Tu e ganhos ZN/TL/CC |

Lista completa em [`firmware/README.md`](../firmware/README.md).

## Atualizações via OTA

Com o computador conectado na rede do Girino:

```bash
# Atualizar o firmware sem cabo USB
pio run -t upload --upload-port 192.168.4.1
```

Ou use a interface web em `http://192.168.4.1/update`.

> **Atenção:** OTA grava apenas o firmware. Mudanças na interface web (`firmware/data/`) exigem `pio run -t uploadfs` via USB.

## Próximos Passos

- [Guia do Firmware](../firmware/README.md) — API REST, pinagem e console serial
- [Atualização OTA](ota-update-guide.md) — detalhes do ElegantOTA
- [Exemplos didáticos](../examples/) — aprender conceitos de controle
- [Hardware](../hardware/) — PCB em KiCad e arquivos de fabricação

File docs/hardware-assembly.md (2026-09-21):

# Montagem do Hardware — Girino

## Lista de Materiais (BOM)

Ver lista completa em [`hardware/bom/`](../hardware/bom/).

## Ferramentas Necessárias

- Ferro de solda e solda
- Multímetro
- Alicate de corte e descascador de fios
- Chaves Philips e Allen

## Diagrama de Ligação

### ESP8266 WROOM — Pinagem

```
                    ┌──────────────┐
         (TX) GPIO1 │              │ GPIO3 (RX)
              GPIO5 │              │ GPIO4
         (D1) ←────│  ESP8266     │────→ (D2)
         Encoder A  │  WROOM      │ Encoder B
                    │              │
              GPIO14│              │ GPIO12
         (D5) ────→│              │←──── (D6)
         Motor IN3  │              │ Motor IN4
                    │              │
              GPIO13│              │ GPIO2
         (D7) ────→│              │←──── (D4)
         Motor ENB  │              │ LED onboard
            PWM     │              │
                    │              │
              3V3   │              │  GND
              3.3V  │              │  GND
                    └──────────────┘
```

### Encoder LPD3806-600BM

| Fio | Cor (típica) | Conexão |
|---|---|---|
| VCC | Vermelho | 5V |
| GND | Preto | GND |
| Canal A | Amarelo | GPIO5 (D1) + pull-up 4,7k para 3.3V |
| Canal B | Verde | GPIO4 (D2) + pull-up 4,7k para 3.3V |

#### ⚠️ Importante: saída em coletor aberto

O LPD3806-600BM tem **saída em coletor aberto** (open-collector): cada canal
não "empurra" o sinal para alto — apenas **puxa o pino para GND** quando o
transistor interno conduz. Sem um resistor de pull-up, o pino do ESP8266
fica **flutuando** e a leitura não funciona.

```
        VCC (5V) ──── LED interno do encoder
        VCC (5V) ──── coletor do transistor (via encoder)
                          │
                      saída A/B ──→ pino do ESP8266
                          │
                     GND (quando conduz)
```

Por isso **cada canal (A e B) precisa de um resistor de pull-up de 4,7k
(ou 10k) conectado ao 3.3V do ESP8266**:

```
  Saída A do encoder ──●────→ D1 (GPIO5)
                       │
                      [R] 4,7k
                       │
  3.3V do ESP8266 ─────┘   (idem para canal B em D2)
```

Regras de segurança:

1. **O pull-up vai para 3.3V, nunca para 5V.** Os GPIOs do ESP8266 não
   são tolerantes a 5V. Como a saída é coletor aberto, o transistor só
   conecta o pino ao GND — a tensão alta do sinal vem do pull-up, então
   mantendo o pull-up em 3.3V o sinal fica seguro.
2. **Por que não usar o pull-up interno do ESP8266?** Ele existe
   (`INPUT_PULLUP`), mas é fraco (~10k–50k, impreciso) e produz bordas
   de subida lentas — em RPM alto, a interrupção perde pulsos. O resistor
   externo de 4,7k dá bordas firmes e contagem confiável.
3. Os resistores já estão soldados na PCB do Girino (ver esquemático em
   `hardware/kicad/`). O firmware usa `pinMode(..., INPUT)` simples,
   confiando nos pull-ups externos.

### Driver do Motor

| Pino Driver | Conexão |
|---|---|
| INB1 (alias IN3) | GPIO14 (D5) |
| INB2 (alias IN4) | GPIO12 (D6) |
| ENB (PWM) | GPIO13 (D7) |
| VCC (Vm) | Fonte 12V do motor |
| VCC (Vcc) | 3.3V (lógica) |
| GND | GND comum |
| OUTB1 / OUTB2 | Motor DC |

Nota: os canais ENA/INA1/INA2/OUTA não são usados pela PCB e ficam
desconectados (ver nets do esquemático).

## Passo a Passo

### 1. Preparação da Fonte

1. Conectar o módulo de conversão de tensão à fonte principal
2. Ajustar a saída para 5V (para o ESP8266 e encoder)
3. Verificar tensão com multímetro

### 2. Montagem do Encoder

1. Fixar o encoder no eixo do motor
2. Conectar os fios conforme tabela acima
3. Verificar que os canais A e B estão em GPIOs com interrupção

### 3. Conexão do Driver do Motor

1. Conectar os pinos de controle ao ESP8266
2. Conectar a saída do driver ao motor DC
3. Alimentar o driver com tensão adequada ao motor

### 4. Conexão do ESP8266

1. Alimentar o ESP8266 com 3.3V (via regulador ou USB)
2. Conectar todos os GNDs em comum
3. Verificar todas as conexões com multímetro antes de ligar

## Verificação

Antes de prosseguir para o firmware:

1. ✅ Todas as conexões GND em comum
2. ✅ Tensões corretas em cada ponto
3. ✅ Nenhum curto-circuito entre VCC e GND
4. ✅ Encoder girando livremente com o motor
5. ✅ ESP8266 ligando (LED onboard piscando)

## Solução de Problemas

| Problema | Causa Provável | Solução |
|---|---|---|
| ESP8266 não liga | Alimentação inadequada | Verificar 3.3V no pino |
| Encoder não conta | Pinos errados ou pull-up ausente | Verificar GPIO5/GPIO4 e os resistores de pull-up 4,7k para 3.3V (coletor aberto exige pull-up externo) |
| Leitura do encoder instável / RPM errado | Pull-up fraco ou para 5V | Confirmar pull-up externo de 4,7k para **3.3V** (não 5V) |
| Motor não gira | Driver sem alimentação | Verificar VCC no driver |
| Motor gira errado | INB1/INB2 invertidos | Trocar conexões INB1 ↔ INB2 |

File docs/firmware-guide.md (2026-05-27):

# Guia do Firmware — Girino

## Compilação

### Com PlatformIO CLI

```bash
cd firmware

# Compilar (verificar erros)
pio run

# Compilar e gravar via USB
pio run -t upload

# Compilar, gravar e abrir monitor serial
pio run -t upload && pio device monitor
```

### Com VSCode + PlatformIO

1. Abra a pasta `firmware/` no VSCode
2. Clique no ícone ✓ (Build) na barra inferior
3. Clique na seta → (Upload) para gravar

## Configuração

### Variáveis de Ambiente (.env)

O firmware usa credenciais WiFi injetadas via build flags. Configure no arquivo `.env`:

```ini
WIFI_SSID="sua_rede_wifi"
WIFI_PASSWORD="sua_senha_wifi"
OTA_PASSWORD="sua_senha_ota"
```

### Configurações do Hardware (config.h)

| Constante | Default | Descrição |
|---|---|---|
| `BAUD_RATE` | 115200 | Velocidade serial |
| `MOTOR_PWM_FREQ` | 1000 | Frequência PWM (Hz) |
| `MOTOR_PWM_RANGE` | 1023 | Resolução PWM (10-bit) |
| `ENCODER_PPR` | 600 | Pulsos por revolução |
| `ENCODER_SAMPLE_MS` | 100 | Intervalo de amostragem do RPM |

### Pinagem (pins.h)

Ver mapeamento completo em [`firmware/include/pins.h`](../firmware/include/pins.h).

## Estrutura do Código

```
firmware/
├── src/
│   ├── main.cpp            # Setup, loop, WiFi, web server, API
│   ├── motor_control.cpp   # Controle PWM do motor
│   └── encoder.cpp         # Leitura do encoder via interrupção
├── include/
│   ├── pins.h              # GPIOs (centralizado — alterar aqui)
│   ├── config.h            # Constantes e configurações
│   ├── motor_control.h     # Interface do módulo motor
│   └── encoder.h           # Interface do módulo encoder
├── platformio.ini          # Configuração PlatformIO
├── .env.example            # Template de credenciais
└── README.md
```

## Monitor Serial

```bash
# Abrir monitor serial
pio device monitor

# Filtrar saída (ex: apenas encoder)
pio device monitor --filter direct
```

Atalhos:
- `Ctrl+]` — Sair do monitor
- `Ctrl+T` — Menu do monitor

## API REST

Ver documentação completa em [`firmware/README.md`](../firmware/README.md#api-rest).

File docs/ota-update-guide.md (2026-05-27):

# Atualização OTA — Girino

O Girino suporta atualização de firmware via Wi-Fi (Over-The-Air), eliminando a necessidade de cabo USB após a primeira gravação.

## Como Funciona

Usamos a biblioteca [ElegantOTA](https://github.com/ayushsharma82/ElegantOTA), que fornece uma interface web para upload do firmware.

## Primeira Gravação (via USB)

A primeira gravação deve ser feita com cabo USB:

```bash
cd firmware
pio run -t upload
```

Após a gravação, o ESP8266 conecta ao Wi-Fi e exibe seu IP no monitor serial.

## Métodos de Atualização OTA

### 1. Interface Web (Recomendado para alunos)

1. Acesse `http://<IP_DO_ESP8266>/update` no navegador
2. Selecione o arquivo de firmware `.bin`
3. Clique em **Upload**
4. Aguarde a reinicialização automática

### 2. PlatformIO (Desenvolvedores)

```bash
# Via mDNS
pio run -t upload --upload-port girino.local

# Via IP
pio run -t upload --upload-port 192.168.1.100
```

### 3. Linha de comando (curl)

```bash
# Gerar o firmware .bin
pio run

# Upload via curl
curl -F "firmware=@.pio/build/girino/firmware.bin" \
     http://192.168.1.100/update \
     -u admin:sua_senha_ota
```

## Segurança

- A senha OTA é configurada no `.env` (`OTA_PASSWORD`)
- Em ambiente de laboratório, use uma senha simples para facilitar
- Para produção, use senha forte e considere HTTPS

## Resolução de Problemas

| Problema | Solução |
|---|---|
| OTA não funciona | Verificar se WiFi está conectado |
| Upload falha | Verificar espaço em flash disponível |
| Device não encontrado | Verificar IP no monitor serial |
| Senha incorreta | Re-gravar via USB com nova senha |

## Verificação

Após atualização OTA bem-sucedida:
1. O LED onboard pisca brevemente
2. O ESP8266 reinicia automaticamente
3. Verificar a versão em `http://<IP>/api/status`

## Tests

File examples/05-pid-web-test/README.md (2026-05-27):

# Exemplo 05 — Teste PID com Interface Web

Exemplo standalone para validar encoder, acionamento do motor e malha PID com ajuste em tempo real pelo navegador.

## Objetivos de Aprendizagem

- Verificar se a pinagem do hardware esta correta
- Ajustar ganhos `Kp`, `Ki`, `Kd` em tempo real
- Visualizar resposta de posicao vs setpoint no grafico

## Pinagem de Referencia (este exemplo)

| GPIO | Pino NodeMCU | Funcao |
|---|---|---|
| GPIO5 | D1 | Encoder Canal A |
| GPIO4 | D2 | Encoder Canal B |
| GPIO14 | D5 | Direcao IN3 |
| GPIO12 | D6 | Direcao IN4 |
| GPIO13 | D7 | PWM ENB |

## Arquivos

- `src/main.cpp` — Firmware de teste com servidor web + PID
- `platformio.ini` — Configuracao PlatformIO do exemplo

## Como executar

1. Edite `src/main.cpp` e ajuste `ssid` e `password`
2. Compile e grave no ESP8266:

```bash
cd examples/05-pid-web-test
pio run -t upload
pio device monitor
```

3. No monitor serial, copie o IP exibido e abra no navegador:

```text
http://<IP_DO_ESP8266>/
```

## Endpoints

| Endpoint | Metodo | Descricao |
|---|---|---|
| `/` | GET | Painel web com ajustes de PID e grafico |
| `/status` | GET | Retorna `posicao` e `setpoint` em JSON |
| `/set` | GET | Atualiza `sp`, `kp`, `ki`, `kd` |

## Checklist de teste rapido

1. Com `setpoint = 0`, confirme motor parado
2. Ajuste `setpoint` para um valor pequeno e confirme movimento
3. Inverta o sinal do `setpoint` e confirme inversao de sentido
4. Verifique se o grafico acompanha `setpoint` e `posicao`

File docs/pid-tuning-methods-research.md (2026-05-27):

# PID Tuning Methods & Control Algorithms — Research Findings

> Comprehensive survey of PID tuning methods used in educational DC motor control platforms, with feasibility analysis for ESP8266 (Girino).

---

## 1. Analysis by Paper

### 1.1 Alexandre et al. (2025) — RET/UEPG

**Full title:** "ANÁLISE DO CONTROLE PID APLICADO NO CONTROLE DE VELOCIDADE DE UM MOTOR CC"

**URL:** https://revistas.uepg.br/index.php/ret/article/view/24725

| Aspect | Details |
|---|---|
| **PID tuning method** | **Cohen-Coon** (open-loop process reaction curve), followed by manual fine-tuning |
| **Control type** | **Speed only** (RPM control) |
| **Implementation** | Discrete PID on ATMEGA328 (Arduino UNO R3) |
| **Motor/hardware** | DC motor + rotary encoder + L298N H-bridge + Arduino UNO |
| **Performance metrics** | ISE, ITAE, IAE, ITSE — all evaluated |
| **Setpoints tested** | 200 RPM, 275 RPM, 120 RPM |
| **Results** | Steady-state error ≈ 0, minimal/no overshoot, consistent rise and settling times |

**Methodology:**
1. **Experimental modeling** — step response of motor to voltage input → transfer function from open-loop data
2. **Cohen-Coon gain calculation** — from process reaction curve parameters (gain K, time constant T, dead time L)
3. **Fine-tuning** — manual adjustment of Kp, Ki, Kd to optimize performance
4. **Validation** — closed-loop control with SCADA monitoring application

**Key takeaway:** Cohen-Coon provided good initial gains, but fine-tuning was essential. The paper demonstrates this is a viable method for DC motor speed control on Arduino-class hardware.

---

### 1.2 Cabral et al. (2025) — Ciência e Natura / UFSM

**Full title:** "Mini bancada de baixo custo com motores CC e encoder para prática de controle realimentado"

**URL:** https://periodicos.ufsm.br/cienciaenatura/article/view/92211

| Aspect | Details |
|---|---|
| **PID tuning method** | **Digital PID in discrete-time (z-domain)**, designed via MATLAB/Simulink |
| **Control type** | **Speed (angular velocity)** |
| **Implementation** | **Discrete-time digital controller**, designed in z-domain |
| **Motor/hardware** | DC motor + encoder + custom low-cost bench |
| **Validation tools** | MATLAB and Simulink |
| **Keywords** | "PID Digital", "Controle discreto", "Função de transferência" |

**Methodology:**
1. Detailed mathematical modeling of DC motor → transfer function derivation
2. **Digital discrete-time controller design** for angular velocity control
3. MATLAB/Simulink simulation and validation
4. Experimental verification on the physical bench

**Key takeaway:** This is the closest paper to Girino conceptually (Brazilian, low-cost, motor+encoder). Uses formal z-domain design (not just heuristic tuning). References Ogata's Discrete-time Control Systems and Reck & Sreenivas (2015). The paper explicitly teaches discrete control design, not just PID tuning heuristics.

---

### 1.3 OpenMCT — Von Chong (2026) — HardwareX

**Full title:** "OpenMCT: an open-source DC motor control educational kit"

**URL:** https://www.sciencedirect.com/science/article/pii/S2468067226000544  
**Zenodo:** https://zenodo.org/records/18409785

| Aspect | Details |
|---|---|
| **PID tuning method** | **Interactive GUI-based tuning** + **direct z-domain difference-equation coefficients** |
| **Control type** | **Speed control** (with current sensing) |
| **Implementation** | **Teensy 4.x** (ARM Cortex-M7, 600 MHz) — much more powerful than ESP8266 |
| **Motor/hardware** | Brushed DC motor + incremental encoder + H-bridge + current sensing |
| **GUI** | Cross-platform Python/Qt GUI with live telemetry, data logging, excitation signals |
| **Control features** | PID + **direct entry of z-domain difference-equation coefficients** |

**Methodology:**
1. Calibration and characterization
2. System identification
3. Controller design and deployment
4. Experimental validation with MATLAB-based tools

**Key features:**
- Supports both PID and raw z-domain control laws
- Students can enter difference-equation coefficients directly
- Complete workflow from identification to controller deployment
- Python GUI for real-time tuning (not embedded auto-tuning)

**Key takeaway:** The most sophisticated platform of the group. Supports z-domain control law implementation — students enter discrete transfer function coefficients directly. Requires a separate Python GUI (not embedded web like Girino). The Teensy 4.x provides ~7.5x more CPU power than ESP8266.

---

### 1.4 MotoShield — Takács et al. (2021) — IEEE FIE/EDUCON

**Full title:** "MotoShield: Open Miniaturized DC Motor Hardware Prototype for Control Education"

**URL:** https://ieeexplore.ieee.org/document/9453979  
**GitHub:** https://github.com/gergelytakacs/AutomationShield

| Aspect | Details |
|---|---|
| **PID tuning method** | **MATLAB-computed PID gains** (likely system identification + analytical design) |
| **Control type** | **Speed control** (RPM tracking) |
| **Implementation** | **Arduino-compatible** (ATmega328/UNO), with MATLAB/Simulink API |
| **Sample time** | **Ts = 30 ms** (Arduino) / **Ts = 40 ms** (MATLAB) |
| **Motor/hardware** | 6V brushed DC motor + hall-effect encoder + L293D H-bridge |
| **PID gains (Arduino example)** | Kp = 3.07, Ki = 122.9, Kd = 0 (PI only) |
| **PID gains (MATLAB example)** | Kp = 0.007, Ti = 0.002, Td = 0.1 |

**Methodology:**
1. System identification via step response
2. PID controller designed in MATLAB using the AutomationShield API
3. Deployed to Arduino for real-time execution
4. Calibration step at 100% PWM for 1 second before control starts

**Implementation details:**
- Uses timer interrupts for precise sampling (30ms = ~33 Hz)
- Absolute (positional) PID form: `PIDAbs.compute(error, 0, 100, 0, 100)`
- Output mapped to 0-100% motor speed
- Speed measurement via encoder pulse counting over sampling window

**Key takeaway:** The MotoShield uses MATLAB-based design deployed to Arduino — gains are computed offline, not auto-tuned on the microcontroller. The sampling rate is relatively low (33 Hz). The Arduino code is simple enough to port to ESP8266.

---

### 1.5 Reck & Sreenivas (2015 ACC / 2016 MDPI)

**Titles:**
- ACC 2015: "Developing a New Affordable DC Motor Laboratory Kit for an Existing Undergraduate Controls Course"
- MDPI Electronics 2016: "Developing an Affordable and Portable Control Systems Laboratory Kit — Results from a Pilot Program"

**URLs:**
- http://rsree.ise.illinois.edu/Control_Education_&_Applications_files/2015ACC_1530_FI.pdf
- https://www.mdpi.com/2079-9292/5/3/36

| Aspect | Details |
|---|---|
| **PID tuning method** | **Analytical design** from first-principles models + step/frequency response identification |
| **Control type** | **Both speed AND position** (multi-experiment) |
| **Implementation** | **Raspberry Pi** with MATLAB/Simulink External Mode |
| **Sample rate** | 100 Hz (position sensor via ADC/SPI) |
| **Motor/hardware** | 12V DC motor + 3D-printed encoder wheel (20 holes) + photo-interrupter + L293D H-bridge + rotary potentiometer (position) |
| **Cost** | ~$130 per kit |

**Laboratory experiments (5 total):**

| Lab | Topic | Control Approach |
|---|---|---|
| Lab 1 | Sensors & DC motor intro | Dead zone, calibration |
| Lab 2 | Simulink + Raspberry Pi | Gain, derivative, integral blocks |
| Lab 3 | First-principles modeling | Measure Ra, La, Kb, KT → transfer function |
| Lab 4 | Step & frequency response ID | First-order model from step + Bode plot |
| Lab 5 | **DC motor control** | **P, PD, P + speed feedback** (NOT full PID!) |

**Key detail:** Lab 5 designs **three controllers: proportional (P), proportional-derivative (PD), and proportional plus speed feedback** — notably, they do NOT use full PID. Students first design analytically, then adjust gains in simulation (because friction makes analytical gains too small), then deploy to hardware.

**Implementation details:**
- Speed measurement: counter blocks counting encoder pulses over 100ms windows
- Position measurement: rotary potentiometer via MCP3002 ADC (SPI)
- Simulink External Mode: code runs on RPi, data viewed live on host PC
- Controller design: pole placement / analytical from transfer function model

**Key takeaway:** This is the foundational work. Uses analytical controller design (P, PD, P+speed feedback), NOT heuristic PID tuning rules. Students derive the transfer function from physical parameters and design controllers to meet specifications. The kit costs ~$130 and uses MATLAB/Simulink as the primary interface.

---

### 1.6 Harahap et al. — ESP8266 PID Motor (Ziegler-Nichols)

**Note:** The exact Harahap et al. paper was not directly accessible, but the search results identified the IEEE paper (10.1109/ICITEED.2024.10469124) with matching description:

**Title:** "PID Controller Design for DC Motor Speed Control"

**URL:** https://ieeexplore.ieee.org/document/10469124  
**Note:** This appears to be the paper referenced. Authors may differ from "Harahap" — exact attribution pending.

| Aspect | Details |
|---|---|
| **PID tuning method** | **Ziegler-Nichols First Method** (open-loop step response / process reaction curve) |
| **Control type** | **Speed control** |
| **Implementation** | DC motor speed control system |
| **Results** | Effective speed regulation, minimized steady-state error, accelerated response times |

**Methodology:**
1. Open-loop step response of the DC motor
2. Extract process parameters from reaction curve
3. Apply Ziegler-Nichols first method formulas to compute Kp, Ki, Kd
4. Validate in closed-loop experiments

**Additional related work (found in search):**

There's a GitHub project "Self-Tuning PID Controller using ESP8266" (https://github.com/manal15iqbal/Self-Tuning-PID-Controller-using-ESP8266) that:
- Uses ESP8266 for PID motor control
- Uses vibration and Back EMF feedback (not encoder!)
- Features real-time monitoring via Python dashboard
- Uses self-tuning mechanism

---

## 2. PID Tuning Methods — Detailed Analysis

### 2.1 Ziegler-Nichols (ZN) Methods

#### 2.1.1 ZN First Method (Open-Loop / Process Reaction Curve)

**How it works:**
1. Apply a step input to the open-loop system
2. Record the output response (process reaction curve)
3. Fit a First-Order Plus Dead Time (FOPDT) model: G(s) = K·e^(-Ls) / (Ts + 1)
4. Extract parameters: K (process gain), T (time constant), L (dead time)
5. Look up PID gains from ZN tables:

| Controller | Kp | Ti | Td |
|---|---|---|---|
| P | T/(K·L) | ∞ | 0 |
| PI | 0.9·T/(K·L) | L/0.3 | 0 |
| PID | 1.2·T/(K·L) | 2·L | 0.5·L |

**Pros:**
- Simple open-loop experiment (safe, no risk of instability)
- Works well for FOPDT-like systems (DC motor is approximately first-order)
- Only needs one step response experiment
- Well-known, extensively documented

**Cons:**
- Assumes FOPDT model — DC motor dead time is usually very small, making L-based formulas fragile
- Quarter-wave decay criterion produces aggressive tuning (~60% overshoot typical)
- Requires manual fine-tuning after initial gains
- Sensitive to noise in step response measurement

**Feasibility on ESP8266:**
- ✅ **Computationally trivial** — only arithmetic operations
- ✅ Can be automated: apply step PWM, record encoder RPM over time, compute K, T, L
- ⚠️ Requires enough memory to store step response data (~100-500 samples)
- ⚠️ Need stable timing for step response measurement (use timer interrupt)
- **Verdict: Fully feasible, recommended for Girino auto-tune**

---

#### 2.1.2 ZN Second Method (Closed-Loop / Ultimate Gain)

**How it works:**
1. Start with proportional-only controller (Ki=0, Kd=0)
2. Gradually increase Kp until sustained oscillations occur
3. Record Kp at oscillation = **Ku** (ultimate gain)
4. Measure oscillation period = **Tu** (ultimate period)
5. Apply ZN frequency-domain formulas:

| Controller | Kp | Ti | Td |
|---|---|---|---|
| P | 0.50·Ku | ∞ | 0 |
| PI | 0.45·Ku | Tu/1.2 | 0 |
| PID | 0.60·Ku | Tu/2 | Tu/8 |
| PID (some OS) | 0.33·Ku | Tu/2 | Tu/3 |
| PID (no OS) | 0.20·Ku | Tu/2 | Tu/3 |

**Standard gain form (PID Classic):**
- Kp = 0.60·Ku
- Ki = 1.2·Ku/Tu
- Kd = 0.075·Ku·Tu

**Pros:**
- Directly measures system dynamics at the critical frequency
- Well-established method
- Works for any system that can sustain oscillations

**Cons:**
- **DANGEROUS** — requires pushing system to sustained oscillation (can damage hardware)
- For DC motors, the oscillation amplitude can cause mechanical stress
- Requires gradual gain increase — time-consuming and potentially risky
- Quarter-wave decay target is aggressive (high overshoot)
- Difficult to automate safely on small hardware

**Feasibility on ESP8266:**
- ⚠️ **Risky for auto-tune** — pushing motor to sustained oscillation can be dangerous
- ⚠️ Requires careful gain ramping logic
- ⚠️ Need oscillation detection algorithm (peak detection)
- ✅ Computationally simple once Ku and Tu are measured
- **Verdict: Possible but NOT recommended for educational/auto-tune use**

---

### 2.2 Cohen-Coon Method

**How it works:**
1. Same open-loop step response as ZN First Method
2. Extract FOPDT parameters: K, T, L
3. Compute r = L/T (controllability ratio)
4. Apply Cohen-Coon formulas (designed to give ¼ decay ratio with minimal load disturbance):

**For PID:**
- Kp = (T/K)·(0.9 + L/(12T)) / (L/T) = (T/K)·(1.0 + R/3) / R  where R = L/T
- Ti = T·(9 + 3R) / (4 + 12R)
- Td = T·(0.5·R) / (1 + 0.5·R)

**Simplified PID formulas (from AutoTunePID library):**
- Kp = 0.8·Ku
- Ki = Kp/(0.8·Tu)
- Kd = 0.194·Kp·Tu

**Pros:**
- **Better than ZN for systems with large dead time** (L/T > 0.1)
- Specifically designed for self-regulating processes
- Provides faster recovery from load disturbances
- Used successfully by Alexandre et al. (2025) for DC motor speed control
- Same experimental procedure as ZN First Method (just different formulas)

**Cons:**
- Still produces aggressive tuning (¼ decay ratio)
- Requires fine-tuning after initial calculation
- More complex formulas than ZN
- For DC motors (which have very small L), the advantage over ZN is minimal

**Feasibility on ESP8266:**
- ✅ **Same as ZN First Method** — identical experimental procedure
- ✅ Computationally trivial (a few multiplications and divisions)
- ✅ Alexandre et al. proved it works on ATMEGA328 (slower than ESP8266)
- **Verdict: Fully feasible, good alternative to ZN First Method**

---

### 2.3 Relay Feedback Auto-Tuning (Åström-Hägglund Method)

**How it works:**
1. Replace PID controller with an on-off relay: u(t) = d·sgn(r(t) - y(t))
2. Relay switches output between +d and -d based on error sign
3. The relay induces a stable limit cycle in the closed loop
4. Measure the amplitude (a) and period (Tu) of the oscillation
5. Compute ultimate gain: **Ku = 4d/(π·a)**
6. Apply ZN frequency-domain rules (or Tyreus-Luyben, etc.)

**Why it's better than ZN Second Method:**
- Oscillation amplitude is **bounded by relay amplitude d** (safe!)
- Can be performed **online** (under closed-loop control)
- **Model-free** — doesn't require fitting K, T, L
- Self-contained — easily automated on microcontroller
- The standard industrial auto-tune method (used in commercial PID controllers)

**Practical considerations:**
- Add small hysteresis ε to prevent chattering from noise
- Choose d large enough that a >> measurement noise
- Discard first 5+ time constants of transient before measuring
- Typically needs 5-10 complete oscillation cycles for good estimates

**Pros:**
- ✅ **Safe** — amplitude bounded by relay output d
- ✅ **Automatable** — can run entirely on microcontroller
- ✅ No need for open-loop experiment or system model
- ✅ Standard method used in commercial auto-tune PID controllers
- ✅ Can be performed online without disconnecting the controller

**Cons:**
- Introduces temporary oscillation (may be undesirable for some processes)
- Describing-function approximation gives ~10% error in Ku estimate
- Requires several oscillation cycles (takes time proportional to system time constant)
- For very fast systems (like DC motor speed), oscillation detection needs fast sampling

**Feasibility on ESP8266:**
- ✅ **Excellent fit** — only needs relay output + peak/valley detection
- ✅ Computationally lightweight: measure peaks, compute a and Tu, then Ku
- ✅ Can be implemented in ~100 lines of C++ code
- ✅ The ESP8266's timer interrupts can handle the sampling
- ⚠️ Need fast enough RPM measurement (encoder ISR) to capture oscillations
- ⚠️ DC motor speed response is fast — sampling at ≥50 Hz recommended
- **Verdict: HIGHLY RECOMMENDED for Girino auto-tune feature**

---

### 2.4 Tyreus-Luyben Method

**How it works:**
- Same experimental procedure as ZN Second Method or relay feedback
- Measure Ku and Tu
- Apply modified formulas designed for **minimal overshoot** and **robustness**:

| Parameter | Formula |
|---|---|
| Kp | Ku/2.2 |
| Ti | 2.2·Tu |
| Td | Tu/6.3 |

**Standard gains:**
- Ki = Kp/Ti = Ku/(2.2·2.2·Tu) = Ku/(4.84·Tu)
- Kd = Kp·Td = Ku·Tu/(2.2·6.3)

**Pros:**
- Much less aggressive than ZN (lower Kp, longer Ti)
- Better robustness margins
- Minimal overshoot compared to ZN Classic

**Cons:**
- Slower response than ZN
- Still needs Ku and Tu (same risks as ZN Second Method unless relay is used)
- Less commonly documented

**Feasibility on ESP8266:**
- ✅ Trivial computation once Ku and Tu are known
- ✅ Best paired with relay feedback for safe Ku/Tu measurement
- **Verdict: Good tuning rule to offer alongside ZN after relay auto-tune**

---

### 2.5 IMC (Internal Model Control) / Lambda Tuning

**How it works:**
1. Obtain FOPDT model: K, T, L from step response or system identification
2. Choose a closed-loop time constant λ (tuning parameter)
3. Compute PID gains:

| Parameter | Formula |
|---|---|
| Kp | T/(K·(λ + L)) |
| Ki | Kp/T = 1/(K·(λ + L)) |
| Kd | Kp·L/2 = T·L/(2·K·(λ + L)) |

- λ = tuning parameter (larger = slower, more robust; smaller = faster)
- λ = T gives "balanced" tuning; λ > T gives conservative; λ < T gives aggressive

**Pros:**
- **Single tuning parameter λ** — intuitive tradeoff between speed and robustness
- Guaranteed stability if model is reasonably accurate
- Explicit control over closed-loop speed
- Well-suited for systems with time delay
- Modern, theoretically sound approach

**Cons:**
- Requires accurate FOPDT model (K, T, L)
- Not directly automatable without system identification step
- Less intuitive for students than ZN/CC tables

**Feasibility on ESP8266:**
- ✅ Computationally trivial
- ⚠️ Requires separate system identification step to get K, T, L
- **Verdict: Good option if step-response system identification is implemented**

---

### 2.6 Comparison of Methods

| Method | Experiment Type | Safety | Automation Ease | Overshoot | DC Motor Suitability |
|---|---|---|---|---|---|
| **ZN 1st (Open-loop)** | Open-loop step | ✅ Safe | ✅ Easy | ~60% (high) | ⚠️ L very small, formulas fragile |
| **ZN 2nd (Closed-loop)** | Sustained oscillation | ❌ Risky | ⚠️ Difficult | ~60% (high) | ⚠️ Risk of motor damage |
| **Cohen-Coon** | Open-loop step | ✅ Safe | ✅ Easy | Moderate | ✅ Proven by Alexandre et al. |
| **Relay Feedback (Åström)** | Relay oscillation | ✅ Bounded | ✅✅ Very easy | Depends on rule applied | ✅✅ Best for auto-tune |
| **Tyreus-Luyben** | Needs Ku, Tu | — | — | Low | ✅ Good with relay feedback |
| **IMC/Lambda** | Needs K, T, L | ✅ Safe | ⚠️ Moderate | Adjustable via λ | ✅ Elegant, model-based |

---

## 3. Existing Arduino PID Auto-Tune Libraries

### 3.1 AutoTunePID (lily-osp)

**URL:** https://github.com/lily-osp/AutoTunePID

**Features:**
- **5 auto-tuning methods:** Ziegler-Nichols, Cohen-Coon, IMC, Tyreus-Luyben, Lambda
- Anti-windup with configurable threshold
- Input/output signal filtering (exponential moving average)
- Multiple oscillation modes (Normal, Half, Mild)
- Fixed 100ms update interval
- ~40 bytes memory per instance
- AUTOSAR C++14 compliant

**Limitations:**
- Requires Arduino Mega 2560 or better (ESP8266 should work)
- 100ms update may be too slow for DC motor speed control (needs 10-50ms)

**Formulas implemented:**

| Method | Kp | Ki | Kd |
|---|---|---|---|
| ZN | 0.6·Ku | 2·Kp/Tu | 0.125·Kp·Tu |
| CC | 0.8·Ku | Kp/(0.8·Tu) | 0.194·Kp·Tu |
| IMC | T/(λ+L) | Kp/T | Kp·L/2 |
| TL | Ku/2.2 | Kp/(2.2·Tu) | Kp·Tu/6.3 |
| Lambda | T/(λ+L) | Kp/T | 0.5·Kp·L |

### 3.2 Arduino PID AutoTune (br3ttb / standard)

**URL:** https://docs.arduino.cc/libraries/pid-autotune/

**Features:**
- Part of the standard Arduino PID ecosystem
- Relay-based auto-tuning
- Works with the standard PID library
- Well-tested, widely used

**Approach:**
- Oscillates the output to determine Ku and Tu
- Then applies ZN rules
- Designed for temperature and slow processes
- May need adaptation for fast motor control

### 3.3 Self-Tuning PID on ESP8266

**URL:** https://github.com/manal15iqbal/Self-Tuning-PID-Controller-using-ESP8266

**Features:**
- Runs entirely on ESP8266
- Uses vibration and Back EMF feedback (no encoder)
- Python dashboard for monitoring
- Demonstrates that ESP8266 can handle PID computation

---

## 4. Recommended PID Implementation for Girino

### 4.1 Recommended Architecture

Based on this research, the recommended approach for Girino:

#### Phase 1: Basic PID with Web Interface
- **Discrete PID** (positional/absolute form) with configurable Kp, Ki, Kd
- **Anti-windup** (back-calculation or clamping)
- **Derivative on measurement** (not on error) to avoid derivative kick
- **Output saturation** (0-100% PWM)
- **Sample time:** 20ms (50 Hz) — fast enough for motor speed, achievable on ESP8266
- Web interface for manual gain entry

#### Phase 2: Auto-Tune via Relay Feedback
- Implement Åström-Hägglund relay feedback auto-tuning
- Procedure:
  1. User triggers auto-tune via web API
  2. System switches to relay mode: PWM = +d or -d based on error sign
  3. Measure 5-10 oscillation cycles
  4. Compute Ku and Tu from peak/valley detection
  5. Apply chosen tuning rule (ZN, Tyreus-Luyben, or CC)
  6. Switch back to PID mode with computed gains
- Relay amplitude: ~50% PWM (configurable)

#### Phase 3: Advanced Options
- Multiple tuning rules selectable via web API
- Step response system identification (for ZN 1st / Cohen-Coon / IMC)
- Gain scheduling for different speed ranges
- Web visualization of step response and tuning process

### 4.2 ESP8266 Feasibility Assessment

| Constraint | Assessment |
|---|---|
| **CPU (80 MHz)** | ✅ PID computation takes ~5-10 μs, well within budget |
| **Timer interrupts** | ✅ Use `timer1_isr` for 20ms sampling — proven technique |
| **Encoder ISR** | ✅ GPIO interrupts for encoder at 600 PPR — feasible at typical motor speeds |
| **Memory** | ✅ PID state ~20 bytes; auto-tune buffer ~200 bytes |
| **WiFi + PID** | ⚠️ WiFi ISR can cause timing jitter; use `noInterrupts()` for critical sections |
| **Web server + PID** | ✅ Handle PID in timer ISR, web server in main loop |
| **Float performance** | ⚠️ ESP8266 has no FPU; float ops ~2-5 μs each. Use fixed-point if needed |

### 4.3 Sample Rate Considerations

| Motor Max RPM | Encoder PPR | Max Pulse Rate | Min Sample Period | Recommended Ts |
|---|---|---|---|---|
| 3000 RPM | 600 | 30 kHz | 33 μs | 10-20 ms |
| 3000 RPM | 600 | 30 kHz | 33 μs | 10-20 ms |
| 1000 RPM | 600 | 10 kHz | 100 μs | 20-50 ms |

**Recommendation:** Ts = 20 ms (50 Hz) — provides good speed resolution while leaving CPU time for WiFi.

---
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

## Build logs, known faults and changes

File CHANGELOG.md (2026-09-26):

# Changelog

Todas as mudanças notáveis neste projeto serão documentadas neste arquivo.

O formato é baseado em [Keep a Changelog](https://keepachangelog.com/pt-BR/1.1.0/),
e este projeto adota [Versionamento Semântico](https://semver.org/lang/pt-BR/).

## [Unreleased]

### Adicionado
- Exemplo `05-pid-web-test` com firmware standalone para teste PID via interface web
- Painel web no exemplo com ajuste em tempo real de `setpoint`, `Kp`, `Ki`, `Kd` e grafico de resposta
- Controle PID em malha fechada no firmware (`pid.cpp`, 50 Hz, anti-windup, derivative-on-measurement)
- Auto-tune embarcado via relay feedback Åström-Hägglund (`pid_autotune.cpp`): identifica Ku e Tu
- Regras de sintonia Ziegler-Nichols, Tyreus-Luyben e Cohen-Coon (`pid_tuning_rules.cpp`)
- Endpoints REST `/api/pid/config`, `/api/pid/start`, `/api/pid/stop`, `/api/pid/autotune`, `/api/pid/tuning`, `/api/pid/tuning/apply` e `/api/pid/response`
- Campo `mode` no `/api/status` (`open-loop`/`pid`/`autotune`) para comparação entre malha aberta e fechada
- Controle de posição (ângulo) com PID bidirecional: `/api/position/config`, `/api/position/start`, `/api/position/stop` e `/api/position/zero`
- Modo **Posição** na interface web (alvo em graus, ganhos próprios, botão "Zerar Posição", gráfico em graus)
- `angle` (graus) no `/api/encoder` e no `/api/status`; campo `mode` aceita `position`
- `stations`, `ssid` e `ip` no `/api/status` (rede do Access Point)
- Exportação CSV do experimento gravado no ESP (`/api/pid/response`), com unidade rpm/graus
- Chart.js embarcado no LittleFS (`data/chart.umd.min.js`) — a interface funciona sem internet
- `scripts/load_env.py`: credenciais do `.env` injetadas corretamente na compilação
- Girino agora opera como **Access Point** (`GIRINO_AP`, `http://192.168.4.1`)
- Feedback do encoder: LED onboard pisca a cada pulso, telemetria serial de 1 Hz (`pulsos`, `p/s`, `rpm`, `ângulo`) e tile "Encoder" na interface com alerta quando o motor roda sem sinal
- Telemetria serial 2 Hz dos controladores ativos: `[PID] SP/RPM/Out`, `[Pos] Alvo/Ângulo/Out` e `[AutoTune] RPM/relay`
- Ganhos default do PID de velocidade calibrados para a bancada (Kp=0.08, Ki=0.25, Kd=0) e aviso na interface quando os ganhos estão zerados
- Console serial de comandos (`help`, `status`, `enc`, `motor`, `pid`, `pos`, `autotune`, `tune`) — controle completo da bancada sem Wi-Fi
- Auto-calibração do sentido motor/encoder: no primeiro movimento após o boot um pulso de teste detecta fiação invertida e corrige em software — "horário" sempre aumenta o ângulo, qualquer que seja a ligação dos fios
- Interface: botões Iniciar/Parar dentro dos painéis de PID e Posição, descrição de cada modo, passo a passo do controle de posição e nota de que o Auto-Tune sugere ganhos para a malha de velocidade
- Interface web redesenhada em **3 abas** (Velocidade / Posição / Manual): o Auto-Tune virou um sub-card dentro da aba Velocidade (fluxo direto identificar → sintonizar → testar), com leitura ao vivo **Setpoint / Medido / Erro / Saída PWM** em destaque, botão **PARAR** fixo no cabeçalho (segurança), tooltips didáticos em Kp/Ki/Kd e box colapsável "Como funciona o PID?"; layout responsivo em 2 colunas em telas ≥ 900px
- **Auto-Tune de posição** (relé simétrico ±d em torno do alvo em graus): identifica a malha de ângulo e gera ganhos em %/° (Ku = 4d/πa) direto para o PID de posição; sub-card próprio na aba Posição, timeout de 90 s (ciclos de posição são mais lentos) e leitura ao vivo do relay ± durante o experimento

### Alterado
- Pinagem de referencia alinhada para motor com `IN3`/`IN4` e `ENB`:
  - `GPIO14 (D5)` -> `IN3`
  - `GPIO12 (D6)` -> `IN4`
  - `GPIO13 (D7)` -> `ENB/PWM`
- Documentacao atualizada com a nova referencia de pinagem em `AGENTS.md`, `firmware/README.md`, `docs/getting-started.md` e `docs/hardware-assembly.md`
- Interface web (`app.js`) conectada ao firmware real (`USE_MOCK=false`); simulador mantido para testes sem hardware
- Leitura do encoder usa `INPUT` confiando nos pull-ups externos de 4,7k para 3.3V (saída coletor aberto do LPD3806)
- Comando manual via `/api/motor` desliga automaticamente PID e auto-tune
- Interface: botão "Aplicar ganhos" removido — os ganhos/setpoint/alvo são enviados ao firmware automaticamente (debounce de 600 ms) ao digitar, ao escolher um método de sintonia (ZN/TL/CC) nos resultados do Auto-Tune e antes do "Iniciar"; mudar o setpoint durante a execução ajusta o alvo ao vivo
- PID refatorado em núcleo único compartilhado entre velocidade (0..+100%) e posição (-100..+100%)
- `/api/pid/tuning` responde chaves minúsculas (`zn`/`tl`/`cc`), consistente com a interface
- Trocar de modo na interface cancela o experimento em andamento no firmware
- Setpoint de velocidade limitado a 3000 RPM (antes 1000) e defaults ajustados à bancada medida (zona morta ~60%, 100% ≈ 1950 RPM): Auto-Tune com amplitude 18% e bias 82% (relay 64–100%), setpoint padrão 1000 RPM, campo de setpoint na UI até 2400 RPM
- PWM do motor para 4 kHz com 8 bits (255 passos) — chiado do chaveamento mais discreto, dentro do orçamento ~1 MHz do PWM por software do ESP8266
- `/api/pid/config` e `/api/position/config` (GET) retornam agora `running`, `error` e `output` (e `measurement` no PID de velocidade); `/api/pid/autotune` (GET) inclui o `output` do relé — alimenta a leitura ao vivo da interface (endpoints de POST inalterados)
- `/api/pid/autotune` (POST) aceita o parâmetro `plant` (`speed` padrão | `position`): em posição usa `target` (graus) como centro da oscilação, relé ±amplitude e ignora `bias`; `autotuneStart()` assinatura nova `(plant, amp, bias, ciclos, setpoint)`; `/api/pid/tuning` e `/api/pid/tuning/apply` aplicam os ganhos no controlador da planta identificada; console serial ganhou `autotune pos <amp> <n> <graus>`

### Corrigido
- Simulador da interface (`USE_MOCK`): o laço de controle agora roda a 50 Hz (5 sub-passos de 20 ms por tick do gráfico, igual ao firmware) — antes simulava a 10 Hz e os ganhos do auto-tune oscilavam em ciclo-limite sustentado na simulação (na bancada convergem); o auto-tune do mock mede o envelope real da oscilação (como o firmware) em vez de usar amplitude estimada fixa
- Planta do mock fiel à bancada real: zona morta ~60% de duty (motor parado abaixo dela, roda-livre como o STOP do L298N), 100% ≈ 1950 RPM, acionamento mínimo ~230 RPM — malha aberta, PID de velocidade, PID de posição e os dois auto-tunes compartilham a mesma planta; o PID de posição com ela reproduz o creep/bang-bang da bancada (documentado na dica da aba Posição)
- Freio dinâmico no L298N para a malha de posição: `MOTOR_DIR_BRAKE` (IN3+IN4 HIGH) + `motorBrake()`; quando a saída do PID de posição está abaixo da zona morta do motor (`POS_MOTOR_DEADZONE_DUTY 60`), o firmware freia o eixo em vez de rodar-livre — mata a inércia do coast que causava o overshoot de cada chute do bang-bang (na simulação: de 1% para 99% do tempo dentro de ±2° do alvo); UI: tile ERRO da posição fica verde quando o erro está dentro da deadband (±2°)
- Posição: atuação em **passos discretos** perto do alvo (modo passo em 3 camadas): deadband/freio → passos curtos a `POS_SOFT_DUTY 65%` com direção pelo sinal do erro e pausa de freio entre passos (`POS_SOFT_KICK_TICKS 1` + `POS_SOFT_REST_TICKS 3` a 50 Hz) → longe, duty mínimo `POS_MIN_DRIVE_DUTY 62` acima da zona morta (pedidos fracos não travam no limiar). Correções no núcleo PID: teto do termo integral da posição (`POS_INTEGRAL_TERM_MAX 55`, abaixo da zona morta — sem rastejo com erro ~0) e teto da contribuição derivativa (`POS_DERIVATIVE_TERM_MAX 30`) — o D a toda velocidade inverteria a saída a cada tick e era a causa principal da caça ±35° medida na bancada; validação numérica: 100% do tempo na faixa ±2° com ganhos default e com ganhos do auto-tune (antes: 0%)
- **Posição v2 (validada em bancada, 9/9)**: o ciclo soco-100%/freio a 50 Hz levou o L298N ao **desligamento térmico** (eixo travou a 171° além do alvo) — duty da malha de posição limitado a `POS_MAX_DUTY 65` (nunca 100%), passos de 2 ticks + descanso de freio de 8 ticks (160 ms) para o driver esfriar; bancada: assentou a **1.8° do alvo com Out=0% e eixo travado**, estável; a caça ±35° de antes era o D explodindo + o driver desligando
- Interface: gráfico movido para o **topo da página** (largura total, abaixo das abas); abaixo dele o painel do modo ativo + status em 2 colunas (desktop) ou empilhados (mobile)
- **Otimização de overshoot validada na bancada (teste agressivo)**: (1) pulso de calibração de sentido amaciado — 70% × 50 ms + freio (`MOTOR_CALIB_*`): giro caiu de **416° para 32-104°** (antes parecia overshoot no gráfico logo ao iniciar); (2) posição ganhou **zona de frenagem antecipada** (`POS_BRAKE_ZONE_*`: com erro < 60° e eixo em movimento, freia antes de entrar nos passos) e duty ajustado para **70%** (`POS_MAX_DUTY` — a curva real medida mostra 65% ≈ 5 RPM instável por atrito estático e 70% ≈ 400 RPM confiável): degrau 0→180° caiu de **48.6° para 4.8°** de overshoot e de 18.5 s para 3.4 s de acomodação; com ganhos agressivos (Kp=5) o overshoot caiu de 29° para ~0°; (3) Kd default do PID de velocidade 0 → **0.005** (overshoot do degrau 500→1500 RPM: 6.7% → 3.7%)
- Documentado na UI e no `AGENTS.md`: **folga mecânica da correia** — o erro residual de posição de ~1-2° é físico (backlash), não do PID; a deadband de ±2° cobre
- Senha do OTA não era aplicada (`ElegantOTA.begin` chamado sem usuário/senha corretos)
- Polaridade do encoder alinhada (horário/FORWARD = ângulo positivo) — pré-requisito do controle de posição
- Aquisição de RPM do laço de controle: janela deslizante de 80 ms + limitador de slew — elimina os picos causados por pulsos perdidos nas rajadas de Wi-Fi do ESP8266
- Malha de velocidade e auto-tune usam o módulo da velocidade (|RPM|) como realimentação — imunes à inversão de fiação; a posição continua usando o ângulo com sinal
- Auto-tune: debounce de cruzamentos (60 ms), envelope medido a partir do 2º cruzamento e período completo (entre cruzamentos pares) — Ku/Tu agora são válidos (antes Tu saía pela metade e a amplitude vinha poluída pelo transiente de partida)
- PWM de 4 kHz com 8 bits validado em bancada (motor gira normalmente, chiado do chaveamento mais discreto)
- Auto-Tune travava em motores com zona morta alta (só zumbia sem girar): relay agora alterna em torno de um pedestal `bias` (default 82%) e Ku usa a amplitude efetiva do degrau; campo Bias na UI e parâmetro `bias` na API
- Interface web travava em "conectando..." no modo AP por depender de Chart.js via CDN
- Auto-Tune: falha/timeout não deixava mais o botão travado; adicionado estado de erro e botão Parar funcional durante o experimento
- Seleção de método de sintonia (ZN/TL/CC) agora preenche os ganhos corretamente
- Capacidade de gravar a interface web (`data/`) com `pio run -t uploadfs`

## [0.1.0] - 2025-05-27

### Adicionado
- Estrutura inicial do repositório
- Firmware skeleton (PlatformIO + ESP8266)
  - Módulo de controle de motor (PWM)
  - Módulo de leitura de encoder (LPD3806-600BM)
  - Módulo OTA (ElegantOTA)
  - Interface web básica
- Templates de documentação
- Exemplos didáticos (placeholders)
- Licenças: GPL-3.0 (firmware), CERN-OHL-S-2.0 (hardware), CC-BY-SA-4.0 (docs)
- Guia de contribuição

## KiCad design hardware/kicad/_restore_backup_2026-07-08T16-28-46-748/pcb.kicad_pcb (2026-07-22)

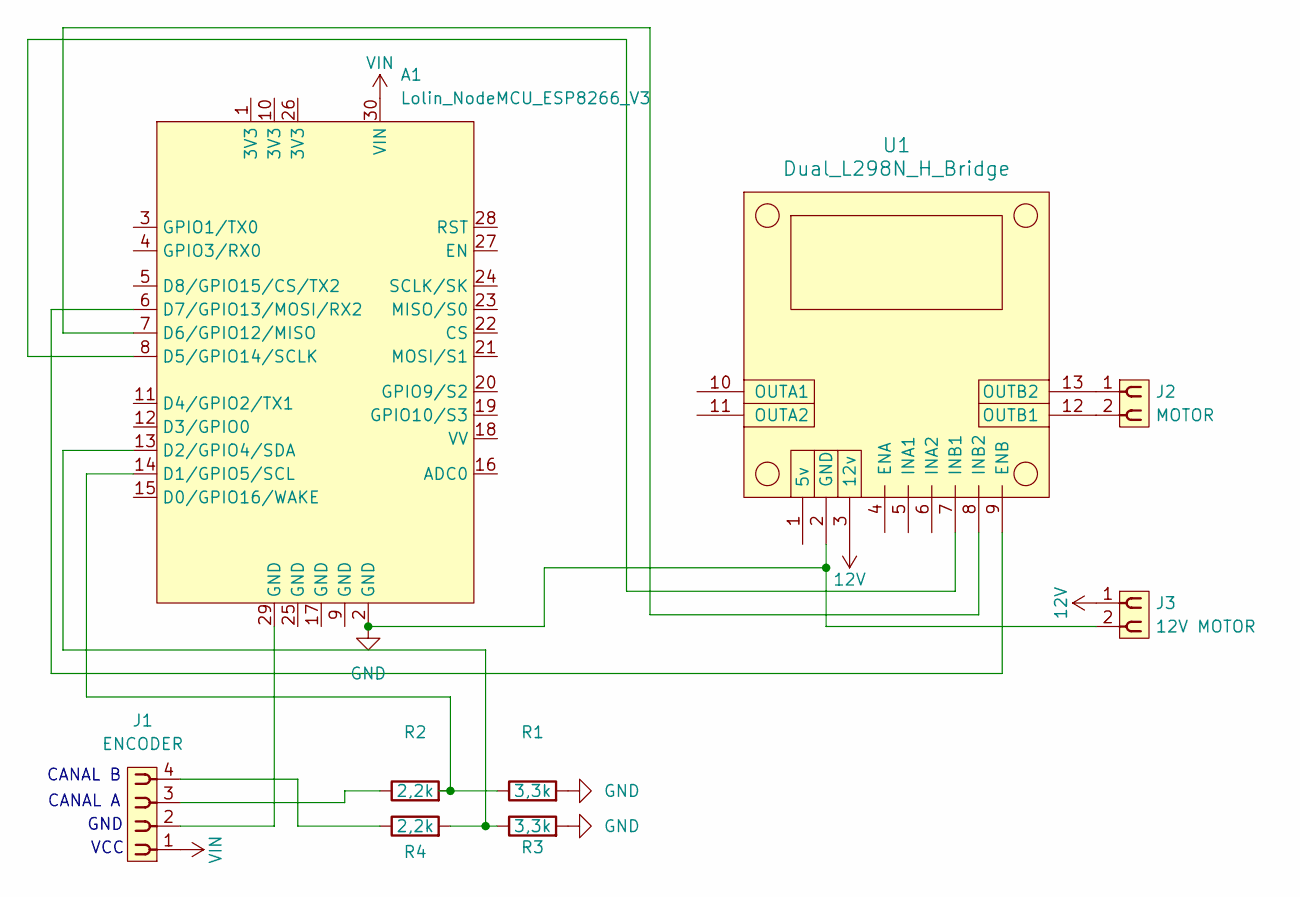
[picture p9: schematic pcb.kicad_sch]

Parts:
A1: Lolin_NodeMCU_ESP8266_V3; Lolin_NodeMCU_ESP8266
J1: ENCODER; PinSocket_1x04_P2.54mm_Vertical
J2: MOTOR; PinSocket_1x02_P2.54mm_Vertical
J3: 12V MOTOR; PinSocket_1x02_P2.54mm_Vertical
R1, R3: 3,3k; R_Axial_DIN0207_L6.3mm_D2.5mm_P10.16mm_Horizontal
R2, R4: 2,2k; R_Axial_DIN0207_L6.3mm_D2.5mm_P10.16mm_Horizontal
U1: Dual_L298N_H_Bridge

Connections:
12V: J3.1, U1.3 (12v)
GND: A1.2 (GND), J3.2, R1.2, R3.2, U1.2 (GND)
unnamed: A1.14 (D1/GPIO5/SCL), R1.1, R2.2
unnamed: A1.13 (D2/GPIO4/SDA), R3.1, R4.2
unnamed: A1.8 (D5/GPIO14/SCLK), U1.7 (INB1)
unnamed: A1.7 (D6/GPIO12/MISO), U1.8 (INB2)
unnamed: A1.6 (D7/GPIO13/MOSI/RX2), U1.9 (ENB)
unnamed: A1.29 (GND), J1.2
unnamed: J1.3, R2.1
unnamed: J1.4, R4.1
unnamed: J2.2, U1.12 (OUTB1)
unnamed: J2.1, U1.13 (OUTB2)
VIN: A1.30 (VIN), J1.1

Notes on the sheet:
VCC
GND
CANAL B
CANAL A

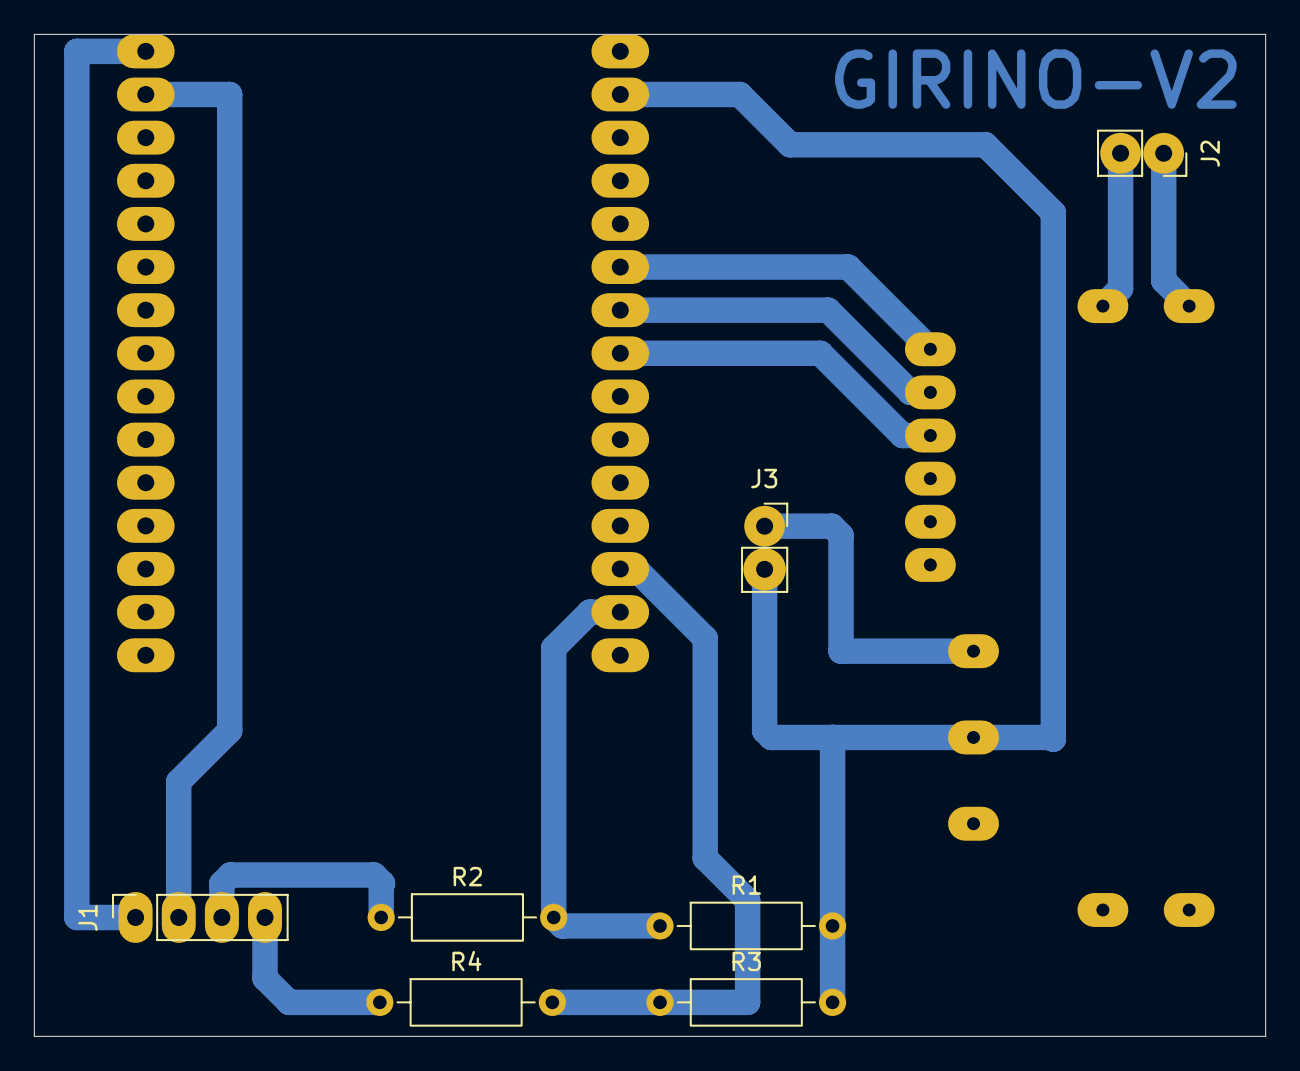
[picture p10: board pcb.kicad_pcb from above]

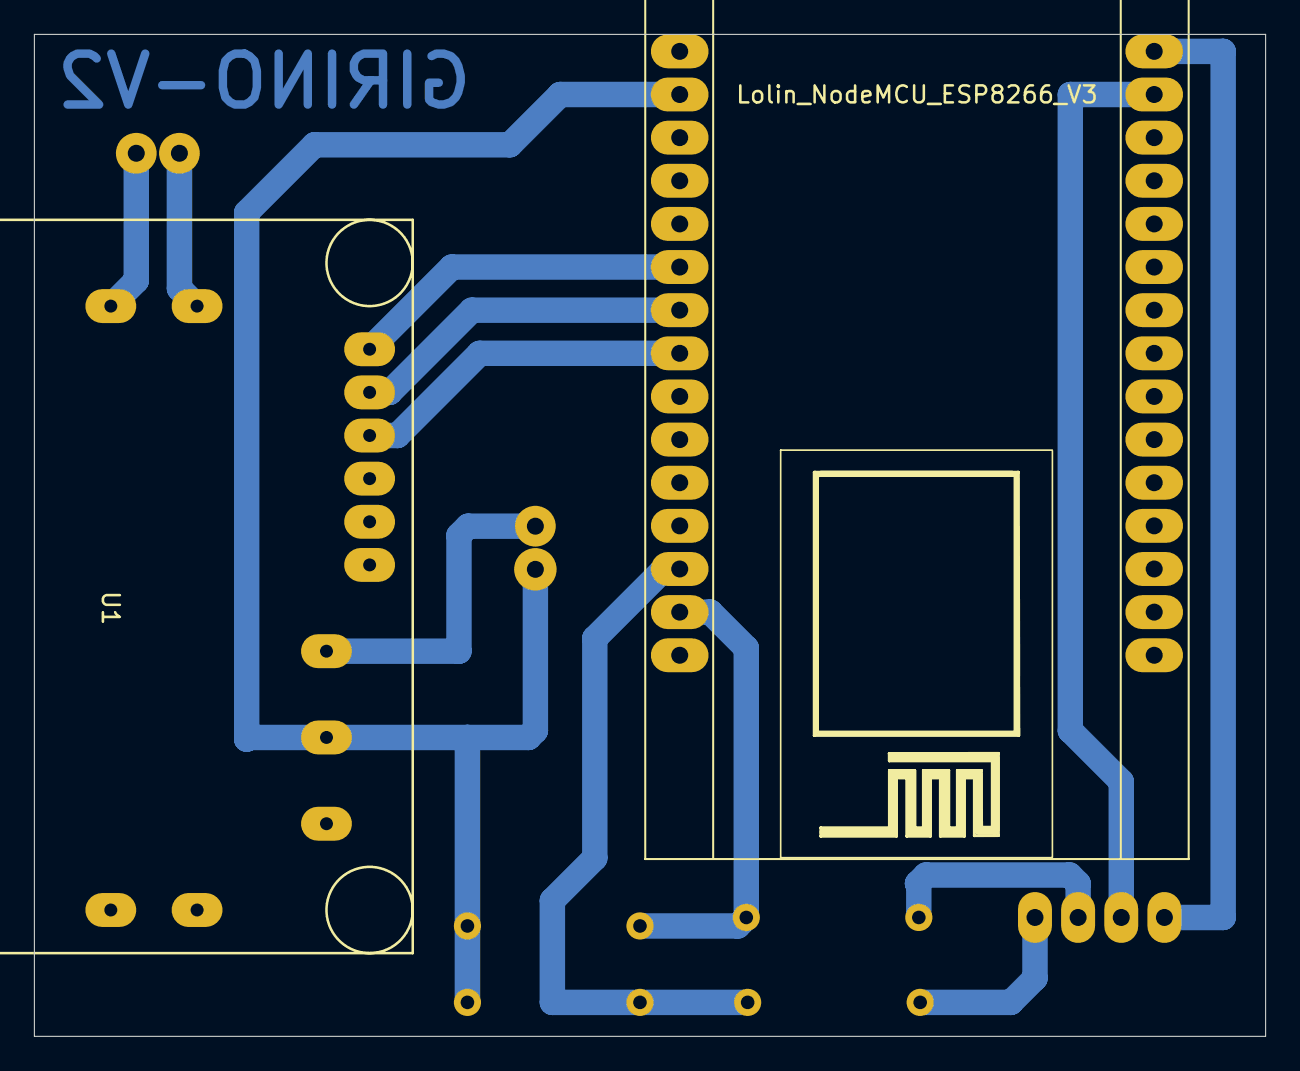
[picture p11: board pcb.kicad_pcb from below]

Board: 2 copper layers, 72.5 x 59.0 mm, 9 parts (2 on the bottom side), 13 nets.

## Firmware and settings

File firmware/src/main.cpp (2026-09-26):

/**
 * Girino — Plataforma didática de controle de motor DC
 * LaRA — Laboratório de Robótica e Automação
 *
 * Firmware principal para ESP8266 WROOM.
 * Integra controle PWM de motor, leitura de encoder incremental,
 * controle PID em malha fechada, auto-tune via relay feedback
 * e atualização OTA via Wi-Fi.
 *
 * Modos de operação (para comparação didática):
 *   - Malha aberta: PWM manual via /api/motor
 *   - Malha fechada: PID via /api/pid/...
 *   - Auto-tune: relay feedback via /api/pid/autotune
 */

#include <Arduino.h>
#include <ESP8266WiFi.h>
#include <ESP8266WebServer.h>
#include <ElegantOTA.h>
#include <LittleFS.h>

#include "pins.h"
#include "config.h"
#include "motor_control.h"
#include "encoder.h"
#include "pid.h"
#include "pid_autotune.h"
#include "pid_tuning_rules.h"
#include "serial_console.h"

// --- Web Server na porta 80 ---
ESP8266WebServer server(80);

// --- Protótipos ---
void setupWiFi();
void setupWebServer();
void handleMotorCommand();
void handleEncoderRead();
void handleStatus();
void handlePidConfig();
void handlePidStart();
void handlePidStop();
void handleAutotune();
void handlePidTuning();
void handlePidTuningApply();
void handlePidResponse();
void handlePositionConfig();
void handlePositionStart();
void handlePositionStop();
void handlePositionZero();
void controlTick(float rpm, float dt);
void recordResponse(unsigned long tMs, float rpm);
void resetResponseBuffer();
String gainsToJson(const PidGains& g);
String posConfigToJson();

// =============================================================
// BUFFER DE RESPOSTA AO DEGRAU
// =============================================================
// Amostras (t, RPM) registradas a cada tick de controle enquanto
// o PID ou o auto-tune estão ativos. Servidas via /api/pid/response.
#define RESPONSE_MAX_POINTS 512
struct ResponsePoint {
    uint16_t tMs;   // offset desde o início do experimento (ms)
    float value;    // medida do experimento (RPM ou graus, conforme unidade)
};
static ResponsePoint responseBuffer[RESPONSE_MAX_POINTS];
static int responseLen = 0;
static unsigned long responseStart = 0;
// Unidade da resposta ao degrau: "rpm" (velocidade) ou "deg" (posição)
static const char* responseUnit = "rpm";

// =============================================================
// SETUP
// =============================================================
void setup() {
    Serial.begin(BAUD_RATE);
    Serial.println();
    Serial.print("=== Girino v");
    Serial.print(FIRMWARE_VERSION);
    Serial.println(" ===");
    Serial.println("LaRA — Laboratório de Robótica e Automação");

    // Inicializar módulos
    motorControlInit();
    encoderInit();
    pidInit();
    autotuneInit();

    // Conectar Wi-Fi
    setupWiFi();

    // Inicializar filesystem
    if (!LittleFS.begin()) {
        Serial.println("[LittleFS] Falha ao montar filesystem");
    } else {
        Serial.println("[LittleFS] Filesystem montado");
    }

    // Configurar servidor web + OTA
    setupWebServer();

    // Console de comandos via serial (USB)
    serialConsoleInit();

    Serial.println("Sistema inicializado com sucesso!");
    Serial.print("Pagina de controle: http://");
    Serial.println(WiFi.softAPIP().toString());
    Serial.print("OTA: http://");
    Serial.println(WiFi.softAPIP().toString() + "/update");
}

// =============================================================
// LOOP
// =============================================================
static unsigned long lastControlTick = 0;
static long lastControlPulses = 0;

void loop() {
    server.handleClient();
    ElegantOTA.loop();
    encoderUpdate();
    encoderUpdateFeedback();  // LED + telemetria do encoder (didático)
    serialConsoleUpdate();    // comandos via serial (USB)

    // Tick de controle em tempo real (50 Hz) — PID e auto-tune
    unsigned long now = millis();
    if (now - lastControlTick >= PID_SAMPLE_MS) {
        float dt = (now - lastControlTick) / 1000.0;
        lastControlTick = now;

        long pulses = encoderGetPulses();
        long delta = pulses - lastControlPulses;
        lastControlPulses = pulses;

        // Janela deslizante (4 ticks = 80 ms): suaviza pulsos perdidos
        // nas rajadas de Wi-Fi, que gerariam picos impossíveis em 20 ms.
        static long deltaRing[CONTROL_RPM_WINDOW_TICKS] = {0};
        static float dtRing[CONTROL_RPM_WINDOW_TICKS] = {0};
        static uint8_t ringIdx = 0;
        deltaRing[ringIdx] = delta;
        dtRing[ringIdx] = dt;
        ringIdx = (ringIdx + 1) % CONTROL_RPM_WINDOW_TICKS;

        long deltaSum = 0;
        float dtSum = 0.0;
        for (int i = 0; i < CONTROL_RPM_WINDOW_TICKS; i++) {
            deltaSum += deltaRing[i];
            dtSum += dtRing[i];
        }
        float rpmRaw = (dtSum > 0.0)
                           ? ((float)deltaSum / (float)ENCODER_PPR) * (60.0 / dtSum)
                           : 0.0;

        // Limitador de slew: o motor não varia mais que CONTROL_RPM_SLEW_MAX
        // por segundo — saltos maiores são ruído de medição e são aparados.
        static float rpmCtrl = 0.0;
        float maxStep = CONTROL_RPM_SLEW_MAX * dt;
        if (rpmRaw > rpmCtrl + maxStep) rpmRaw = rpmCtrl + maxStep;
        if (rpmRaw < rpmCtrl - maxStep) rpmRaw = rpmCtrl - maxStep;
        rpmCtrl = rpmRaw;

        controlTick(rpmCtrl, dt);
    }
}

/**
 * Tick de controle: decide quem aciona o motor.
 * Prioridade: auto-tune > posição > velocidade (PID) > malha aberta.
 */
void controlTick(float rpm, float dt) {
    // Telemetria didática (2x/s) enquanto um controlador está ativo —
    // permite acompanhar o experimento pelo monitor serial.
    static unsigned long lastTelemetry = 0;
    unsigned long nowMs = millis();
    bool verbose = (nowMs - lastTelemetry >= 500);
    if (verbose) lastTelemetry = nowMs;

    if (autotuneIsRunning()) {
        if (autotuneGetPlant() == AUTOTUNE_PLANT_POSITION) {
            // Relay bidirecional na malha de posição: oscila em torno do
            // alvo em graus. Saída com sinal define o sentido de giro.
            float angle = encoderGetAngle();
            autotuneCompute(angle, dt);
            float out = autotuneGetRelayOutput();
            if (out >= 0.0) {
                motorSetDirection(MOTOR_DIR_FORWARD);
                motorSetSpeed((int)out);
            } else {
                motorSetDirection(MOTOR_DIR_REVERSE);
                motorSetSpeed((int)(-out));
            }
            recordResponse(millis() - responseStart, angle);
            if (verbose) Serial.printf("[AutoTune] Alvo=%.1f Angulo=%.1f relay=%.0f%%\n",
                                       posGetTarget(), angle, out);
        } else {
            // Relay unidirecional na malha de velocidade: usa o módulo da
            // velocidade para ficar imune à inversão de fiação motor/encoder.
            float rpmAbs = fabs(rpm);
            autotuneCompute(rpmAbs, dt);
            float out = autotuneGetRelayOutput();
            motorSetDirection(MOTOR_DIR_FORWARD);
            motorSetSpeed((int)out);
            recordResponse(millis() - responseStart, rpmAbs);
            if (verbose) Serial.printf("[AutoTune] RPM=%.0f relay=%.0f%%\n", rpmAbs, out);
        }

        // Experimento terminou?
        if (autotuneIsDone() || autotuneIsFailed()) {
            motorSetSpeed(0);
            motorSetDirection(MOTOR_DIR_STOP);
        }
    } else if (posIsRunning()) {
        // Malha de posição — atuação em camadas (bang-bang com passos):
        //   1. deadband (±2°), ou o PID pedindo repouso -> FREIO dinâmico;
        //   2. perto do alvo (< 30°): PASSOS discretos — KICK ticks de
        //      chute + REST ticks de freio; direção pelo SINAL DO ERRO;
        //   3. longe: duty fixo POS_MAX_DUTY (65%) — NUNCA 100%: o soco
        //      com ciclos de freio a 50 Hz levou o L298N ao desligamento
        //      térmico na bancada (eixo travou a 171° além do alvo).
        static int softPhase = 0;
        float angle = encoderGetAngle();
        float error = posGetTarget() - angle;
        float out = posCompute(angle, dt);
        float rpmAbs = fabsf(rpm);

        if (fabsf(error) <= POS_DEADBAND_DEG || fabsf(out) < POS_DRIVE_EPS) {
            motorBrake();
            softPhase = 0;
        } else if (fabsf(error) < POS_BRAKE_ZONE_DEG && rpmAbs > POS_BRAKE_ZONE_RPM) {
            // Frenagem antecipada: ainda longe do alvo mas em movimento —
            // freia ANTES de entrar na zona de passos, senão a velocidade
            // de entrada atravessa o alvo (overshoot).
            motorBrake();
            softPhase = 0;
        } else if (fabsf(error) < POS_SOFT_NEAR_DEG) {
            if (softPhase < POS_SOFT_KICK_TICKS) {
                if (error > 0) {
                    motorSetDirection(MOTOR_DIR_FORWARD);
                    motorSetSpeed(POS_MAX_DUTY);
                } else {
                    motorSetDirection(MOTOR_DIR_REVERSE);
                    motorSetSpeed(POS_MAX_DUTY);
                }
                softPhase++;
            } else if (softPhase < POS_SOFT_KICK_TICKS + POS_SOFT_REST_TICKS) {
                motorBrake();
                softPhase++;
            } else {
                softPhase = 0;
            }
        } else {
            softPhase = 0;
            // Direção pela saída do PID (sinal), duty na região confiável
            if (out >= 0.0) {
                motorSetDirection(MOTOR_DIR_FORWARD);
                motorSetSpeed(POS_MAX_DUTY);
            } else {
                motorSetDirection(MOTOR_DIR_REVERSE);
                motorSetSpeed(POS_MAX_DUTY);
            }
        }
        recordResponse(millis() - responseStart, angle);
        if (verbose) Serial.printf("[Pos] Alvo=%.1f Angulo=%.1f Out=%.0f%%\n", posGetTarget(), angle, out);
    } else if (pidIsRunning()) {
        // A malha de velocidade é unidirecional (só horário): usa o módulo
        // da velocidade como realimentação — assim continua regulando mesmo
        // se a fiação do motor/encoder estiver invertida.
        float rpmAbs = fabs(rpm);
        float out = pidCompute(rpmAbs, dt);
        motorSetDirection(MOTOR_DIR_FORWARD);
        motorSetSpeed((int)out);
        recordResponse(millis() - responseStart, rpmAbs);
        if (verbose) Serial.printf("[PID] SP=%.0f RPM=%.0f Out=%.0f%%\n", pidGetSetpoint(), rpmAbs, out);

        // Aviso didático: giro no sentido oposto ao esperado pela fiação.
        static bool polarityWarned = false;
        if (rpm < -50.0 && !polarityWarned) {
            polarityWarned = true;
            Serial.println("[PID] Aviso: motor gira ao contrario da fiacao esperada — verifique motor/encoder");
        }
    }
    // Sem PID nem auto-tune: motor segue o último comando manual
    // (tratado em handleMotorCommand) — malha aberta para comparação.
}

// =============================================================
// BUFFER DE RESPOSTA
// =============================================================
void resetResponseBuffer() {
    responseLen = 0;
    responseStart = millis();
}

/**
 * Define a unidade da resposta ao degrau ("rpm" ou "deg").
 * Usado pelos controladores (web e console serial).
 */
void setResponseUnit(const char* unit) {
    responseUnit = unit;
}

void recordResponse(unsigned long tMs, float value) {
    if (responseLen >= RESPONSE_MAX_POINTS) return;
    responseBuffer[responseLen].tMs = (uint16_t)tMs;
    responseBuffer[responseLen].value = value;
    responseLen++;
}

// =============================================================
// Implementações — Wi-Fi e servidor
// =============================================================

void setupWiFi() {
    // Modo Access Point: o Girino cria sua própria rede Wi-Fi.
    // Vantagem didática: alunos conectam direto pelo celular ou
    // notebook, sem depender de roteador, internet ou credenciais
    // de rede externa. O IP fixo 192.168.4.1 é o endereço da página.
    WiFi.mode(WIFI_AP);

    // IMPORTANTE: configurar o IP ANTES de subir o AP. Se chamado
    // depois, o servidor DHCP embutido não reinicia e os clientes
    // conectam sem receber endereço IP.
    IPAddress ip = AP_LOCAL_IP;
    WiFi.softAPConfig(ip, ip, IPAddress(255, 255, 255, 0));

    // Senha do AP precisa ter >= 8 caracteres; caso contrário,
    // sobe uma rede aberta (sem senha) para não bloquear a aula.
    const char* apPass = WIFI_PASSWORD;
    bool apOpen = (strlen(apPass) < 8);
    bool ok;
    if (apOpen) {
        ok = WiFi.softAP(WIFI_SSID);
        Serial.println("[WiFi] Senha do AP curta (<8 chars) — rede aberta!");
    } else {
        ok = WiFi.softAP(WIFI_SSID, apPass);
    }

    if (ok) {
        Serial.printf("[WiFi] Access Point '%s' ativo\n", WIFI_SSID);
        Serial.printf("[WiFi] IP: %s\n", WiFi.softAPIP().toString().c_str());
    } else {
        Serial.println("[WiFi] Falha ao criar Access Point!");
    }
}

void setupWebServer() {
    // Arquivos estáticos do LittleFS
    server.serveStatic("/style.css", LittleFS, "/style.css");
    server.serveStatic("/app.js", LittleFS, "/app.js");
    // Chart.js local — o modo AP não tem internet, então a lib não
    // pode vir de CDN; ela é servida do próprio LittleFS.
    server.serveStatic("/chart.umd.min.js", LittleFS, "/chart.umd.min.js");

    // Página principal — servir index.html do LittleFS
    server.on("/", HTTP_GET, []() {
        File file = LittleFS.open("/index.html", "r");
        if (file) {
            server.streamFile(file, "text/html");
            file.close();
        } else {
            server.send(404, "text/plain", "index.html nao encontrado no LittleFS");
        }
    });

    // API: Comando do motor (malha aberta)
    server.on("/api/motor", HTTP_POST, handleMotorCommand);

    // API: Leitura do encoder
    server.on("/api/encoder", HTTP_GET, handleEncoderRead);

    // API: Status do sistema
    server.on("/api/status", HTTP_GET, handleStatus);

    // API: PID
    server.on("/api/pid/config", HTTP_GET, handlePidConfig);
    server.on("/api/pid/config", HTTP_POST, handlePidConfig);
    server.on("/api/pid/start", HTTP_POST, handlePidStart);
    server.on("/api/pid/stop", HTTP_POST, handlePidStop);
    server.on("/api/pid/response", HTTP_GET, handlePidResponse);

    // API: Auto-tune (relay feedback) e regras de sintonia
    server.on("/api/pid/autotune", HTTP_GET, handleAutotune);
    server.on("/api/pid/autotune", HTTP_POST, handleAutotune);
    server.on("/api/pid/tuning", HTTP_GET, handlePidTuning);
    server.on("/api/pid/tuning/apply", HTTP_POST, handlePidTuningApply);

    // API: Controle de posição (ângulo)
    server.on("/api/position/config", HTTP_GET, handlePositionConfig);
    server.on("/api/position/config", HTTP_POST, handlePositionConfig);
    server.on("/api/position/start", HTTP_POST, handlePositionStart);
    server.on("/api/position/stop", HTTP_POST, handlePositionStop);
    server.on("/api/position/zero", HTTP_POST, handlePositionZero);

    // OTA com senha
    ElegantOTA.begin(&server, "admin", OTA_PASSWORD);
    ElegantOTA.setAutoReboot(true);

    server.begin();
    Serial.println("Servidor HTTP + OTA iniciado");
}

// =============================================================
// Handlers — malha aberta, encoder e status
// =============================================================

void handleMotorCommand() {
    if (!server.hasArg("direction") || !server.hasArg("speed")) {
        server.send(400, "application/json", "{\"error\":\"missing parameters\"}");
        return;
    }

    // Comando manual desliga PID, auto-tune e posição (modo comparação)
    pidStop();
    autotuneCancel();
    posStop();

    String direction = server.arg("direction");
    int speed = server.arg("speed").toInt();

    if (direction == "forward") {
        motorSetDirection(MOTOR_DIR_FORWARD);
        motorSetSpeed(speed);
    } else if (direction == "reverse") {
        motorSetDirection(MOTOR_DIR_REVERSE);
        motorSetSpeed(speed);
    } else if (direction == "stop") {
        motorSetSpeed(0);
    } else {
        server.send(400, "application/json", "{\"error\":\"invalid direction\"}");
        return;
    }

    String json = "{\"direction\":\"" + direction + "\",\"speed\":" + String(speed) + "}";
    server.send(200, "application/json", json);
}

void handleEncoderRead() {
    long pulses = encoderGetPulses();
    float rpm = encoderGetRPM();
    float angle = encoderGetAngle();

    String json = "{\"pulses\":" + String(pulses) + ",\"rpm\":" + String(rpm, 1) +
                  ",\"angle\":" + String(angle, 1) + "}";
    server.send(200, "application/json", json);
}

void handleStatus() {
    String json = "{";
    json += "\"version\":\"" FIRMWARE_VERSION "\",";
    json += "\"wifi_rssi\":" + String(WiFi.RSSI()) + ",";
    json += "\"stations\":" + String(WiFi.softAPgetStationNum()) + ",";
    json += "\"ssid\":\"" + String(WIFI_SSID) + "\",";
    json += "\"ip\":\"" + WiFi.softAPIP().toString() + "\",";
    json += "\"uptime_ms\":" + String(millis()) + ",";
    json += "\"free_heap\":" + String(ESP.getFreeHeap()) + ",";
    json += "\"angle\":" + String(encoderGetAngle(), 1) + ",";
    json += "\"mode\":\"";
    if (autotuneIsRunning()) json += "autotune";
    else if (posIsRunning()) json += "position";
    else if (pidIsRunning()) json += "pid";
    else json += "open-loop";
    json += "\"";
    json += "}";
    server.send(200, "application/json", json);
}

// =============================================================
// Handlers — PID
// =============================================================

String pidConfigToJson() {
    String json = "{";
    json += "\"kp\":" + String(pidGetKp(), 4) + ",";
    json += "\"ki\":" + String(pidGetKi(), 4) + ",";
    json += "\"kd\":" + String(pidGetKd(), 4) + ",";
    json += "\"setpoint\":" + String(pidGetSetpoint(), 1) + ",";
    json += "\"running\":" + String(pidIsRunning() ? "true" : "false") + ",";
    // Leitura ao vivo para a interface (didático): medida, erro e saída
    json += "\"measurement\":" + String(pidIsRunning() ? fabs(encoderGetRPM()) : 0.0f, 1) + ",";
    json += "\"error\":" + String(pidIsRunning() ? pidGetSetpoint() - fabs(encoderGetRPM()) : 0.0f, 1) + ",";
    json += "\"output\":" + String(pidGetOutput(), 1) + ",";
    json += "\"mode\":\"";
    json += pidIsRunning() ? "pid" : "open-loop";
    json += "\"";
    json += "}";
    return json;
}

void handlePidConfig() {
    if (server.method() == HTTP_GET) {
        server.send(200, "application/json", pidConfigToJson());
        return;
    }

    // POST: configura ganhos e setpoint (setpoint em RPM)
    if (!server.hasArg("kp") || !server.hasArg("ki") || !server.hasArg("kd")) {
        server.send(400, "application/json", "{\"error\":\"missing gains\"}");
        return;
    }

    float kp = server.arg("kp").toFloat();
    float ki = server.arg("ki").toFloat();
    float kd = server.arg("kd").toFloat();
    float setpoint = server.hasArg("setpoint") ? server.arg("setpoint").toFloat()
                                               : pidGetSetpoint();

    if (setpoint < 0.0 || setpoint > PID_MAX_SETPOINT) {
        server.send(400, "application/json", "{\"error\":\"invalid setpoint\"}");
        return;
    }

    pidConfigure(kp, ki, kd, setpoint);
    server.send(200, "application/json", pidConfigToJson());
}

void handlePidStart() {
    motorSetDirection(MOTOR_DIR_FORWARD);
    posStop();               // posição e velocidade não rodam juntos
    autotuneCancel();
    responseUnit = "rpm";
    resetResponseBuffer();
    pidStart();
    server.send(200, "application/json", "{\"ok\":true,\"mode\":\"pid\"}");
}

void handlePidStop() {
    pidStop();
    motorSetSpeed(0);
    motorSetDirection(MOTOR_DIR_STOP);
    server.send(200, "application/json", "{\"ok\":true,\"mode\":\"open-loop\"}");
}

void handlePidResponse() {
    // Em modo posição o alvo é o ângulo; em velocidade, o RPM.
    float sp = (strcmp(responseUnit, "deg") == 0) ? posGetTarget()
                                                  : pidGetSetpoint();

    String json = "{\"data\":[";
    for (int i = 0; i < responseLen; i++) {
        if (i > 0) json += ",";
        float t = (float)responseBuffer[i].tMs / 1000.0;
        json += "[" + String(t, 3) + "," +
                String(sp, 1) + "," +
                String(responseBuffer[i].value, 1) + "]";
    }
    json += "],\"setpoint\":" + String(sp, 1);
    json += ",\"unit\":\"" + String(responseUnit) + "\"";
    json += "}";
    server.send(200, "application/json", json);
}

// =============================================================
// Handlers — Auto-tune (relay feedback)
// =============================================================
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

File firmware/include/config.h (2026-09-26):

/**
 * config.h — Constantes e configurações do firmware Girino
 */

#ifndef CONFIG_H
#define CONFIG_H

#include "pins.h"

// --- Versão do firmware ---
#define FIRMWARE_VERSION "0.1.0"

// --- Serial ---
#ifndef BAUD_RATE
#define BAUD_RATE 115200
#endif

// --- Wi-Fi (Access Point) ---
// O Girino opera como Access Point: cria sua própria rede para que
// os alunos conectem direto pelo navegador, sem roteador nem internet.
// Credenciais sobrescritáveis via build_flags (.env).
// IMPORTANTE: a senha do AP precisa ter no mínimo 8 caracteres.
#ifndef WIFI_SSID
#define WIFI_SSID "GIRINO_AP"
#endif

#ifndef WIFI_PASSWORD
#define WIFI_PASSWORD "girino123"
#endif

#ifndef OTA_PASSWORD
#define OTA_PASSWORD "girino"
#endif

// IP fixo do Girino na rede do AP (gateway para os clientes conectados)
#define AP_LOCAL_IP IPAddress(192, 168, 4, 1)

// --- Motor ---
// PWM por software do ESP8266: o core limita frequência x passos a ~1 MHz.
// 4 kHz x 255 passos (8-bit) deixa o chiado do chaveamento mais discreto
// e mantém 0,4% de resolução de duty.
// Bancada medida: zona morta ~60%, 100% -> ~1950 RPM (10 V no motor).
#define MOTOR_PWM_FREQ     4000    // Frequência PWM em Hz
#define MOTOR_PWM_RANGE    255     // Resolução PWM (8-bit)
#define MOTOR_MAX_SPEED    100     // Velocidade máxima em %

// --- Pulso de calibração do sentido da fiação ---
// Pulso curto no primeiro movimento após o boot para descobrir o sentido
// físico motor/encoder. Curva real medida na bancada: zona morta ~65%,
// joelho íngreme (70% -> ~400 RPM) — não dá para calibrar devagar sem o
// atrito estático travar. Estratégia: pulso de 70% por 50 ms (giro
// ~45-60°, ~80+ pulsos — limiar: 30) SEGUIDO DE FREIO, que mata a
// inércia (antes, roda-livre + 100%/150 ms girava 400°+ = mais de uma
// volta, parecia overshoot no gráfico logo ao iniciar).
#define MOTOR_CALIB_DUTY     70
#define MOTOR_CALIB_MS       50
#define MOTOR_CALIB_BRAKE_MS 40

// --- Encoder LPD3806-600BM ---
#define ENCODER_PPR        600     // Pulsos por revolução
#define ENCODER_SAMPLE_MS  100     // Intervalo de amostragem para cálculo de RPM

// --- Feedback do encoder (didático) ---
// O LED onboard pisca a cada pulso recebido — dá para conferir a
// fiação/leitura do encoder sem abrir o navegador.
#define ENCODER_LED_ACTIVITY_MS   60     // Tempo que o LED fica aceso (ms)
#define ENCODER_DEBUG_INTERVAL_MS 1000   // Telemetria no serial (ms); 0 desativa

// --- Direções do motor ---
#define MOTOR_DIR_FORWARD   1
#define MOTOR_DIR_REVERSE  -1
#define MOTOR_DIR_STOP      0    // roda-livre (L298N: IN3=IN4=LOW, EN=0)
#define MOTOR_DIR_BRAKE     2    // freio dinâmico (L298N: IN3=IN4=HIGH)

// --- PID / Auto-Tune ---
#define PID_SAMPLE_MS       20      // Período de amostragem do PID (50 Hz)
#define PID_OUTPUT_MAX      100.0   // Saída máxima do PID (% PWM)
#define PID_OUTPUT_MIN      0.0     // Saída mínima do PID (% PWM)
#define PID_MAX_SETPOINT    3000.0  // Limite de setpoint de velocidade (RPM)
#define PID_MAX_PPR_WINDOW  20.0    // Janela de leitura do encoder (ms) p/ RPM do PID

// --- Aquisição de velocidade no laço de controle ---
// O Wi-Fi do ESP8266 bloqueia interrupções em rajadas, então contagens
// de 20 ms podem perder pulsos e "pular". A janela deslizante e o
// limitador de slew rejeitam essas leituras impossíveis.
#define CONTROL_RPM_WINDOW_TICKS 4      // janela deslizante (4 x 20 ms = 80 ms)
#define CONTROL_RPM_SLEW_MAX     8000.0 // aceleração máxima plausível (RPM/s)
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

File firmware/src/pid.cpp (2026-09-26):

/**
 * pid.cpp — Núcleo PID compartilhado (velocidade e posição)
 *
 * Educational notes (for the students):
 *
 * The controller uses the standard positional form, discretized:
 *
 *   u[k] = Kp * e[k] + Ki * integral(e) + Kd * derivative
 *
 * Two practical details matter for real motors:
 *
 * 1. ANTI-WINDUP: when the motor saturates (e.g. 100% PWM during a big
 *    step), the integral term would keep growing ("windup") and cause a
 *    huge overshoot when the setpoint is finally reached. We handle it
 *    two ways: (a) conditional integration — the integral is frozen while
 *    the output is saturated in the same direction of the error — and
 *    (b) a hard clamp on the integral as a last resort.
 *
 * 2. DERIVATIVE ON MEASUREMENT: differentiating the error causes a
 *    "derivative kick" every time the setpoint changes. Differentiating
 *    the measurement instead (with a negative sign) gives the same
 *    regulation effect without the kick.
 *
 * O mesmo núcleo é usado por dois controladores:
 *   - velocidade: saída 0..+100% (somente horário)
 *   - posição:    saída -100..+100% (bidirecional)
 */

#include <Arduino.h>
#include "pid.h"
#include "motor_control.h"

// --- Núcleo genérico de um controlador PID ---
struct PidCore {
    PidState state;
    float kp, ki, kd;
    float setpoint;
    float integral;
    float prevMeasurement;
    float output;
    float outMin, outMax;
    float integralTermMax;     // teto da contribuição integral (% de saída)
    float derivativeTermMax;   // teto da contribuição derivativa (% de saída)
    bool firstSample;  // primeiro passo após start: sem derivada
};

static PidCore speedPid;
static PidCore posPid;

static void coreInit(PidCore& c, float outMin, float outMax) {
    c.state = PID_IDLE;
    c.kp = c.ki = c.kd = 0.0;
    c.setpoint = 0.0;
    c.integral = 0.0;
    c.prevMeasurement = 0.0;
    c.output = 0.0;
    c.outMin = outMin;
    c.outMax = outMax;
    c.integralTermMax = outMax;        // por padrão, sem teto extra
    c.derivativeTermMax = outMax;      // por padrão, sem teto do D
    c.firstSample = true;
}

static void coreReset(PidCore& c) {
    c.integral = 0.0;
    c.prevMeasurement = 0.0;
    c.output = 0.0;
    c.firstSample = true;
}

static float coreCompute(PidCore& c, float measurement, float dt) {
    if (dt <= 0.0) return c.output;

    // No primeiro passo após o start, memoriza a medição atual para
    // que a derivada não dê um "salto" (0 -> medição real).
    if (c.firstSample) {
        c.prevMeasurement = measurement;
        c.firstSample = false;
    }

    float error = c.setpoint - measurement;

    // --- Integral with anti-windup ---
    float newIntegral = c.integral + error * dt;

    // --- Derivative on measurement ---
    // Teto da CONTRIBUIÇÃO derivativa (em % de saída, não no de/dt cru):
    // com o eixo a toda velocidade o de/dt passa de 10.000 °/s e o termo
    // D sozinho inverteria a saída a cada tick. O clamp mantém o
    // amortecimento sem o soco.
    float derivative = -(measurement - c.prevMeasurement) / dt;
    float dTerm = c.kd * derivative;
    if (c.derivativeTermMax < c.outMax) {
        dTerm = fmaxf(-c.derivativeTermMax,
                      fminf(c.derivativeTermMax, dTerm));
    }

    // --- Raw output ---
    float rawOutput = c.kp * error + c.ki * newIntegral + dTerm;

    // --- Saturation / anti-windup (conditional integration) ---
    bool saturatedHigh = rawOutput > c.outMax;
    bool saturatedLow  = rawOutput < c.outMin;
    bool pushingHigh   = error > 0.0;
    bool pushingLow    = error < 0.0;

    if ((saturatedHigh && pushingHigh) || (saturatedLow && pushingLow)) {
        // Do not integrate while pushing further into saturation
        newIntegral = c.integral;
        rawOutput = c.kp * error + c.ki * newIntegral + dTerm;
    }

    // Hard clamp on the integral as a last resort.
    // O teto da CONTRIBUIÇÃO integral (integralTermMax, em % de saída)
    // limita o que o termo Ki*I consegue sozinho — na malha de posição,
    // manter o termo integral abaixo da zona morta do motor evita que o
    // motor fique acionado para sempre com erro ~0 (rastejo além do alvo).
    float integralMin = c.outMin / (c.ki > 0.0 ? c.ki : 1.0);
    float integralMax = c.outMax / (c.ki > 0.0 ? c.ki : 1.0);
    if (c.integralTermMax < c.outMax) {
        integralMax = fminf(integralMax, c.integralTermMax / (c.ki > 0.0 ? c.ki : 1.0));
        integralMin = fmaxf(integralMin, -integralMax);
    }
    if (newIntegral > integralMax) newIntegral = integralMax;
    if (newIntegral < integralMin) newIntegral = integralMin;

    c.integral = newIntegral;
    c.prevMeasurement = measurement;

    // Final clamp
    if (rawOutput > c.outMax) rawOutput = c.outMax;
    if (rawOutput < c.outMin) rawOutput = c.outMin;
    c.output = rawOutput;

    return c.output;
}

void pidInit() {
    coreInit(speedPid, PID_OUTPUT_MIN, PID_OUTPUT_MAX);
    coreInit(posPid, POS_OUTPUT_MIN, POS_OUTPUT_MAX);
    posPid.integralTermMax = POS_INTEGRAL_TERM_MAX;      // abaixo da zona morta do motor
    posPid.derivativeTermMax = POS_DERIVATIVE_TERM_MAX;  // sem soco do D em alta velocidade
    Serial.println("[PID] Inicializado");
    Serial.println("[Pos] Controle de posicao inicializado (angulo)");
}

// =============================================================
// PID de velocidade
// =============================================================

void pidConfigure(float kp, float ki, float kd, float setpoint) {
    speedPid.kp = kp;
    speedPid.ki = ki;
    speedPid.kd = kd;
    speedPid.setpoint = setpoint;

    coreReset(speedPid);

    Serial.print("[PID] Config: Kp=");
    Serial.print(kp);
    Serial.print(" Ki=");
    Serial.print(ki);
    Serial.print(" Kd=");
    Serial.print(kd);
    Serial.print(" SP=");
    Serial.println(setpoint);
}

void pidStart() {
    coreReset(speedPid);
    speedPid.state = PID_RUNNING;
    Serial.println("[PID] Controle em malha fechada iniciado");
}

void pidStop() {
    speedPid.state = PID_IDLE;
    coreReset(speedPid);
    Serial.println("[PID] Controle parado");
}

bool pidIsRunning() {
    return speedPid.state == PID_RUNNING;
}

float pidCompute(float measurement, float dt) {
    if (speedPid.state != PID_RUNNING) return 0.0;
    return coreCompute(speedPid, measurement, dt);
}

float pidGetKp() { return speedPid.kp; }
float pidGetKi() { return speedPid.ki; }
float pidGetKd() { return speedPid.kd; }
float pidGetSetpoint() { return speedPid.setpoint; }
float pidGetOutput() { return speedPid.output; }

// =============================================================
// PID de posição (ângulo)
// =============================================================
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

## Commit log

2026-05-27 feat: estrutura inicial do projeto Girino
    - Firmware skeleton (PlatformIO + ESP8266): controle PWM, leitura de encoder LPD3806-600BM, OTA via ElegantOTA, interface web com API REST
    - Estrutura de diretórios: firmware/, hardware/, mechanical/, docs/, examples/, gallery/
    - Documentação: getting-started, hardware-assembly, firmware-guide, ota-update-guide
    - Exemplos didáticos: basic-motor-control, encoder-reading, pid-speed-control, ota-web-update
    - Licenças: GPL-3.0 (firmware), CERN-OHL-S-2.0 (hardware), CC-BY-SA-4.0 (docs)
    - Templates: CONTRIBUTING.md, CHANGELOG.md, .gitignore, .env.example
2026-05-27 docs: adicionar plano do módulo PID com auto-tune e comparação de métodos
    - docs/plano-pid.md: planejamento completo do PID
    - 5 métodos de sintonia (ZN, TL, CC, relay feedback, manual)
    - Fluxo de auto-tune via relay feedback (Åström-Hägglund)
    - Arquitetura do firmware (novos arquivos pid.h/cpp, pid_autotune.h/cpp)
    - Novos endpoints API REST para PID
    - Componentes da interface web (gráfico Chart.js)
    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
2026-05-27 feat: adicionar exemplo de teste PID web e alinhar pinagem
2026-05-29 feat: adcionado arquivos da kicad do esquematico e da pcb
    [pcb.kicad_pcb, pcb.kicad_sch]
2026-06-03 feat : feito os arquivos de pcb e de fabricação via flatcam
    [.step, pcb.kicad_pcb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]
2026-06-19 fix : corrige erro de orientação nos arquivos gerber
    [pcb.kicad_pcb, pcb.kicad_sch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]
2026-06-22 feat: interface web com simulador mock para controle de motor
    - Adiciona index.html, style.css e app.js servidos via LittleFS
    - Mobile-first, dark mode, Chart.js para gráfico em tempo real
    - Simulador mock: motor first-order, PID, auto-tune relay feedback
    - Modos: malha aberta, PID manual, auto-tune (ZN/TL/CC)
    - Corrige build_flags duplicados no platformio.ini
    - Remove ESP8266WebServer de lib_deps (já no framework)
    - Corrige ICACHE_RAM_ATTR -> IRAM_ATTR em encoder.cpp
    - LittleFS inicializado em main.cpp com serveStatic
    WIP: interface funcional mas precisa de melhorias significativas
    na usabilidade, visual e integração com firmware real.
    [app.js, encoder.cpp, main.cpp]
2026-06-22 refactor: unificar controles no card de modo, setpoint fixo no PID
    - Move botões Iniciar/Pausar/Parar para header do gráfico (icon-only)
    - Funde mode-panel e open-loop-panel com hr separador
    - Move setpoint para mode-panel (visível só em PID)
    - RPM e Pulsos no chart-footer, dados estáticos no status inferior
    - Adiciona .card-divider, .btn-ctrl, .chart-stat no CSS
    [app.js]
2026-06-22 fix: setpoint no gráfico só aparece no modo PID
    - Passa null para setpoint quando não está em modo PID/Auto-Tune
    - spanGaps:false no dataset setpoint (Chart.js ignora nulls)
    - Setpoint no footer mostra '--' quando em malha aberta
    [app.js]
2026-06-23 refactor: unificar PID/Auto-Tune no card de modo, limpar gráfico
    - Move PID e Auto-Tune para dentro do mode-panel (uma única section)
    - Remove status-badge 'Parado' do chart-footer
    - Remove _updateRunStatus() e todas as chamadas
    - Adiciona setSetpointVisible() no ChartManager
    - Esconde dataset setpoint + legenda em malha aberta
    - Mostra linha tracejada constante em PID/Auto-Tune
    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
2026-06-23 fix: setpoint aparece no gráfico e footer ao clicar Aplicar
    - _onApplyPid() atualiza statSetpoint.textContent imediatamente
    - Flag setpointConfigured controla exibição do setpoint no gráfico
    - Setpoint no gráfico aparece quando PID/Auto-Tune + configurado
    - Reset setpointConfigured ao mudar para malha aberta
    [app.js]
2026-07-22 fix:tirando o divisor de tensão e adcionando a forma correta de leitura do encoder
    [caixa.step, pcb.kicad_pcb, pcb.kicad_sch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]
2026-09-21 fix: injetar credenciais do .env na compilacao
    O PlatformIO nao interpolava \ do .env nas build_flags (compilava
    com credenciais vazias). Um extra_script (scripts/load_env.py) le o .env,
    remove aspas e injeta os -D de SSID/senha/OTA.
2026-09-21 feat: PID de velocidade/posicao, auto-tune relay e regras de sintonia
    - pid.cpp: nucleo unico compartilhado (anti-windup, derivada na medicao),
    velocidade 0..+100% e posicao -100..+100% com zona morta em graus
    - pid_autotune.cpp: relay feedback com pedestal (bias) para vencer a zona
    morta do motor, debounce de cruzamentos e periodo completo
    - pid_tuning_rules.cpp: Ziegler-Nichols, Tyreus-Luyben e Cohen-Coon
2026-09-21 feat: console serial de comandos
    Permite controlar a bancada sem Wi-Fi pelo monitor serial (115200):
    help, status, enc, motor, pid, pos, autotune, tune.
2026-09-21 feat: firmware como Access Point, controle de posicao e robustez da bancada
    - Wi-Fi: modo Access Point (GIRINO_AP / 192.168.4.1), com softAPConfig
    antes do softAP para o DHCP entregar IP aos clientes
    - Posicao (angulo): endpoints /api/position/*, PID bidirecional no laço
    de controle e angulo no /api/encoder e /api/status
    - Aquisicao do RPM de controle: janela deslizante de 80 ms + limitador de
    slew (pulsos perdidos nas rajadas de Wi-Fi geravam picos impossiveis)
    - Velocidade/auto-tune usam |RPM| (imunes a inversao de fiacao)
    - Auto-calibracao do sentido no primeiro movimento (pulso de teste);
    fiacao invertida e corrigida em software
    - Feedback do encoder: LED a cada pulso e telemetr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
    [config.h, encoder.cpp, main.cpp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]
2026-09-21 feat: interface web com modo posicao, grafico local e melhorias de usabilidade
    - Chart.js embarcado no LittleFS (funciona sem internet no modo AP)
    - Modo Posicao: alvo em graus, ganhos proprios, zerar posicao e grafico
    em graus; botoes Iniciar/Parar dentro dos paineis de PID e Posicao
    - Descricao de cada modo, passo a passo do zerar e aviso de ganhos zerados
    - Correcoes: auto-tune nao trava em falha/timeout, Parar durante o
    experimento, troca de modo cancela o ensaio, sintonia ZN/TL/CC preenche
    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
2026-09-21 docs: atualizar README, AGENTS, changelog e roadmap
    - firmware/README: modo AP, uploadfs obrigatorio, console serial e
    auto-calibracao do sentido
    - AGENTS: comandos (uploadfs), endpoints de posicao, driver L298N e
    caracteristicas medidas da bancada
    - CHANGELOG: registra as features e correcoes desta rodada
    - plano-pid: checkboxes de PID/auto-tune/sintonia concluidos
    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
2026-09-26 feat: auto-tune de posição, interface em 3 abas e documentação UERJ Sem Muros
    - Auto-Tune de posição via relay feedback simétrico (plant=position) e leitura
    ao vivo nos GETs de config/autotune
    - PID de posição v2: freio dinâmico (MOTOR_DIR_BRAKE), atuação em passos
    discretos, zona de frenagem antecipada e duty limitado a 70% (POS_MAX_DUTY)
    - Interface web redesenhada em 3 abas (Velocidade/Posição/Manual), gráfico no
    topo, PARAR fixo no cabeçalho, envio automático de ganhos e box didático do PID
    - Simulador (USE_MOCK) fiel à bancada: 50 Hz, zona morta ~60%, 100% ≈ 1950 RPM
    - Pulso de calibração de sentido amaciado (70% x 50 ms + freio)
    - Kd default do PID de veloc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
    [app.js, config.h, main.cpp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]
2026-09-26 docs: atualizar README raiz e getting-started com o estado atual
    - Status: firmware validado em bancada, PCB KiCad, caixa 3D e 5 exemplos
    - Funcionalidades: Access Point, PID velocidade/posição, auto-tune e console serial
    - Início rápido: .env do AP, uploadfs obrigatório e OTA em 192.168.4.1
    - Novas seções no README: Bancada medida e infográfico UERJ Sem Muros
    - getting-started: boot real do firmware, pull-ups 4,7k e driver L298N

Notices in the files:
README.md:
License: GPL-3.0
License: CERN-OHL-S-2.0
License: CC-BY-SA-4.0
